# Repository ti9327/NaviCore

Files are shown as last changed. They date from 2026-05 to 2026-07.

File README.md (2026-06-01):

<div align="center">

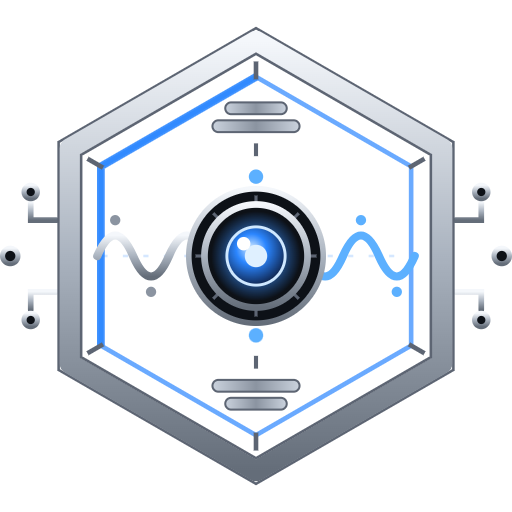
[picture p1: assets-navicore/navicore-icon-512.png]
NaviCore


# NaviCore

**Astromech Animation Controller**

[**🚀 Launch the config tool →**](https://greghulette.github.io/NaviCore/)

</div>

---

WCB-based RC controller firmware for ESP32-S3 (WCB HW 3.2). Reads SBUS from an
RC receiver, dispatches matrix buttons / switches / knobs to local and remote
Maestros and WCB boards over ESP-NOW, and ships with a browser-based config
tool that talks to the board over Web Serial.

## Features

- SBUS input (16 or 24 channel, auto-detected) on Serial1 (UART1)
- SBUS output passthrough on a dedicated hardware UART (UART0, GPIO9) — byte-tee
  of the RX stream, sub-millisecond latency (~1 byte-time)
- Local Pololu Maestro on Serial2 (UART2)
- Up to 8 remote Maestros via WCBStream broadcast over ESP-NOW
- WCB unicast and broadcast command dispatch
- Multi-mode (3-position switch) button / switch / knob mapping, NVS-backed
- Multi-tap detection (single / double / triple) with exclusive or cumulative
  dispatch
- USB Serial JSON protocol for config tool and CLI debugging

## Layout

```
NaviCore.ino         Main sketch
rc_config.h          Config struct, JSON serialisation, NVS persistence
wcb_config.h         WCB board ID / port definitions
sbus_reader.h        SBUS decoder + passthrough tee
config_tool/         Browser-based config GUI (Web Serial)
assets-navicore/     NaviCore brand assets (logo, favicon, app icons)
model/               FrSky X18 transmitter model file (download below)
```

## Required libraries

Install via the Arduino Library Manager:

- `ArduinoJson` (Benoit Blanchon) v6.x
- `Adafruit NeoPixel`

Local libraries (drop into your sketchbook `libraries/` folder):

- `WCBClient` + `WCBStream`
- `PololuMaestro`
- `hcr`

## Downloads

### FrSky X18 transmitter model

NaviCore assumes a specific channel map (SBUS channels 1–15 for
sticks/switches, CH7 for the button matrix, etc.). To save you setting all
that up by hand on your X18, the matching transmitter model file is bundled
in the [`model/`](model) folder.

- [**Download:** r2 web gui.bin](<model/r2 web gui.bin>) — ~2.4 KB

Copy it to the `MODELS/` folder on the X18's SD card, then load it from the
transmitter's model select screen.

## Configuration tool

Open [`config_tool/index.html`](config_tool/index.html) directly in a
Chromium-based browser (Chrome, Edge). Click **Connect**, pick the board's
serial port, and you get live PWM monitoring, button mapping, switch / knob
config, calibration, and CSV import/export.

The tool uses the [Web Serial API](https://developer.mozilla.org/en-US/docs/Web/API/Web_Serial_API)
— no install, no server, no Electron app.

## USB serial JSON protocol

Newline-delimited JSON on the USB Serial port:

| Command | Reply |
|---|---|
| `PING` | `{"type":"PONG"}` |
| `GET_CONFIG` | `{"type":"CONFIG","data":{...}}` |
| `{"type":"SET_CONFIG","data":{...}}` | `{"type":"ACK","ok":true}` |
| `{"type":"START_MONITOR"}` | streams `PWM_UPDATE` every 50 ms |
| `{"type":"STOP_MONITOR"}` | `{"type":"ACK","ok":true}` |
| `{"type":"RESET_DEFAULTS"}` | reloads factory defaults, replies ACK |
| `{"type":"TRIGGER","mode":1,"btn":3,"tap":1}` | fires virtual button press |
| `{"type":"WCB_SEND","target":2,"cmd":":PP100"}` | manually fires WCB command |

## Brand

NaviCore's mark is a machined hexagon housing a glowing photoreceptor, with the
RC signal arriving as a waveform (steel in, blue out). Logo, favicon, mono, and
app-icon assets live in [`assets-navicore/`](assets-navicore).

## License

MIT — see [LICENSE](LICENSE).

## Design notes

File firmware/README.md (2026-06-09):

# Firmware Binaries

This folder hosts the compiled NaviCore firmware for the **WCB v3.2**
hardware (ESP32-S3). The browser-based flasher in `config_tool/index.html`
(Config → Firmware tab) pulls the latest set from here on `main` via the
GitHub Contents API.

## Versioning

The firmware version is stored in `fw_version.h` at the repo root:

```c
#define FW_VERSION_BASE  "v0.2.0"         // bump by hand for releases
#define FW_VERSION_DTG   "211520QMAY26"   // auto-stamped by pre-commit hook
#define FW_VERSION       FW_VERSION_BASE "_" FW_VERSION_DTG
```

- **`FW_VERSION_BASE`** — semver version (MAJOR.MINOR.PATCH).  Edit by hand
  when cutting a new release: `v0.2.0` → `v0.2.1` → `v0.3.0` → `v1.0.0`.
  The build scripts treat the field as opaque — any quoted string works,
  so two-digit forms (`v0.1`) still parse if you need them.
- **`FW_VERSION_DTG`** — stamped automatically by `tools/git-hooks/pre-commit`
  on every commit, same DTG format as the UI footer in `config_tool/index.html`.
  Both files always reflect the same commit time.
- **`FW_VERSION`** — convenience macro the firmware uses to report itself
  in the `PONG` reply and at boot.

The build script reads both `#define`s and embeds them in the bin filename
(e.g. `NaviCore_v0.2.0_211520QMAY26_ESP32S3.bin`), so the file on disk,
the file's reported version at runtime, and the source header all match.

## File naming

Three files per release, all ending with these stable suffixes:

| File suffix | Flash address | What it is |
|---|---|---|
| `_ESP32S3.bin` | `0x10000` | Application image (`ota_0`)|
| `_ESP32S3_boot.bin` | `0x0` | Second-stage bootloader |
| `_ESP32S3_part.bin` | `0x8000` | Partition table |

The flasher matches by **suffix**, so the version prefix can change every
build without touching the page. Example set:

```
NaviCore_201500RMAY26_ESP32S3.bin
NaviCore_201500RMAY26_ESP32S3_boot.bin
NaviCore_201500RMAY26_ESP32S3_part.bin
```

The Config → Firmware tab offers two buttons:

- **⬆ Update Firmware** — routine update. NVS at `0x9000` is never touched,
  so the user's saved configuration survives.  The flasher auto-detects
  whether app-only is safe (matching partition table) or a full
  bootloader+partition+app write is needed (layout changed) — either way,
  NVS is preserved.
- **⚠ Full Wipe & Flash** — initial push / recovery.  Writes the full image
  AND erases NVS (`0x9000`, 20 KB) and OTA data (`0xE000`, 8 KB), returning
  the board to factory-fresh state.  Use this for first-time programming on
  a new board, or to recover from corrupted config / bad partition state.
  **Erases all saved settings.**

## How to update the binaries

**Default: GitHub Actions does it automatically.**  Every push to any
branch triggers `.github/workflows/build-firmware.yml`, which compiles
`NaviCore.ino` for ESP32-S3 with the `min_spiffs` partition scheme,
reads `FW_VERSION_BASE` + `FW_VERSION_DTG` out of `fw_version.h`, and
commits the three resulting bins back to `firmware/` (overwriting older
versioned files) under an auto-commit tagged `[skip ci]`.  Once that
commit lands on `main`, the Config → Firmware tab can flash any
connected board.

The two manual options below remain available for offline work or for
producing a one-off bin without going through CI.

### Option A — Arduino IDE (zero scripting)

1. Open `NaviCore.ino` in Arduino IDE.
2. Tools → Board → **ESP32S3 Dev Module** (or whatever you normally use for WCB v3.2).
3. Tools → Partition Scheme → **Minimal SPIFFS (1.9MB APP with OTA / 190KB SPIFFS)**.
4. Tools → PSRAM → **OPI PSRAM** — **required**; the firmware allocates its
   runtime config in external PSRAM and halts at boot (solid red status LED)
   without it.
5. Sketch → **Export Compiled Binary** (Ctrl/Cmd+Alt+S).
6. The IDE writes three files into `build/<fqbn>/`:
   - `NaviCore.ino.bin`
   - `NaviCore.ino.bootloader.bin`
   - `NaviCore.ino.partitions.bin`
7. Copy them into `firmware/`, renaming with a version prefix + the suffixes
   in the table above. Example:
   ```
   cp build/.../NaviCore.ino.bin             firmware/NaviCore_<DTG>_ESP32S3.bin
   cp build/.../NaviCore.ino.bootloader.bin  firmware/NaviCore_<DTG>_ESP32S3_boot.bin
   cp build/.../NaviCore.ino.partitions.bin  firmware/NaviCore_<DTG>_ESP32S3_part.bin
   ```
   (Old versioned files can be deleted or left as history — the flasher only
   looks at suffixes, so it always picks one of each.)
8. Commit to `main`. The Config → Firmware tab will pick them up automatically.

### Option B — `tools/build-firmware.ps1` (Windows) or `build-firmware.sh` (Linux/macOS/WSL)

Wraps `arduino-cli` so steps 2–6 above happen in one command.  Same
logic the CI workflow uses, just running locally.

```powershell
# Windows:
pwsh tools/build-firmware.ps1
```
```bash
# Linux / macOS / WSL:
tools/build-firmware.sh
```

Both read `FW_VERSION_BASE` + `FW_VERSION_DTG` from `fw_version.h`,
compile with the right FQBN + partition scheme, prune older bins, and
drop the new ones into `firmware/` with the matching version prefix.
You commit + push manually after a local build.

Prereqs: `arduino-cli` on `PATH`, the `esp32` core installed
(`arduino-cli core install esp32:esp32@3.3.4`), and the same library set
the CI workflow installs (see `.github/workflows/build-firmware.yml`).

## Notes

- Only **WCB v3.2** (ESP32-S3) is supported by the in-browser flasher right
  now. If support for older boards is added later, mirror the WCB Wizard's
  per-variant suffix scheme (`_ESP32.bin`, `_ESP32_boot.bin`, etc.) and add
  a board-variant dropdown to the Firmware tab.
- The flasher auto-detects whether the board is blank, has matching
  partitions, or needs a full flash. App-only is the default for any
  already-programmed board with a matching partition table.
- The page fetches from `main` by default. Developers can override the
  branch by setting `localStorage.rc_fw_branch = '<branch-name>'` in DevTools.

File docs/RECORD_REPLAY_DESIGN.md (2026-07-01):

# NaviCore Record / Replay — Design Spec (v2, validated)

Status: **DESIGN — validated against code, ready for phase-1 build.**
Last updated 2026-06-30. v2 folds in a 22-agent validation pass (see §12 changelog).

## Goal

Capture everything the droid *does* (Maestro moves, HCR, WCB commands, MP3, aux serial) over a
bounded window, save it as a named **clip**, replay it on demand, and build a renamable **library**
of clips. Phase 2 adds a **timeline editor** in the config tool. The phase-1 data model is designed
so phase 2 is purely additive.

## Decisions locked

1. **Servo anti-snap:** snapshot last-commanded positions at clip start (`servoHome`) → ease-in.
2. **Storage:** a **dedicated `clips` partition** carved from the 16 MB flash (OTA + config untouched).
3. **Motion smoothness:** prioritized — **dense keyframe capture (no thinning) + replay interpolation**.
4. **Trigger:** **button-first**. `toggle` is the universal button mode; `level`/`hold` need a switch.

---

## 1. Event model — a clip event is a timestamped `RcAction`

Every button/switch maps to an **`RcAction`** (`{type, target[6], cmd[96], fn, chan, track, note}`,
rc_config.h) that the config tool already renders (action picker) and serializes
(`actionToJson`/`actionFromJson`). So **clip event = `{ tMs, RcAction }`**, and the phase-2 editor is
that picker on a timeline.

### Capture taps (verified) — both route through ONE queue

| Tap | Captures | Core |
|---|---|---|
| `rcExecuteActionNow()` (NaviCore.ino:926) | Every discrete action (WCB uni/broadcast, Maestro, Serial, HCR, MP3) | **Core 1 AND Core 0** ⚠ |
| `processKnobs()` sinks — `maestroSetTarget` (:1196), `dispatchHcrVolume` (:1199) | Continuous gimbal/knob streams (synthesized as `setTarget`/`SetVolume` events) | Core 1 |

⚠ **`rcExecuteActionNow` runs on Core 0** for a remote ESP-NOW TRIGGER (`onWCBCommand` →
`rcTelemetry::handle` → `rcDispatch` → `rcExecuteActionNow`, rc_telemetry.h:863-871, no defer to
loop). It also runs on Core 1 (local press, `checkPendingActions`, Web-Serial TRIGGER). This dual-core
reachability **dictates the recorder's concurrency design** (§6) — it is the exact class of bug that
crashed the board during the OTA work.

---

## 2. Clip structure — baseline header + event list

The header snapshots the **global state** the events silently depend on.

| Header field | Why |
|---|---|
| `version, name[32], durationMs, createdDtg` | Metadata (tool stamps real date on save). |
| `mode` (1–3) | Context. |
| `boardType` + `auxBaud[3]` | A clip replayed on the *other* board profile (v2 PCB vs WCB 3.2) would mis-route / mis-speed local serial; record so the tool can warn on mismatch. |
| `hcrDest` {transport, target[6], wcbPort} | HCR actions carry only `fn/chan/track`; destination is **global**. |
| `mp3Dest` {transport, target[6]} | Same — MP3 destination is global. |
| `maestros[8]` {type, device} | Maestro actions carry a **logical slot id**; wiring + Pololu device # live here. |
| `hcrLocalVol[3]`, `mp3LocalVolume` | Volume **shadows** — restore before replay so relative *volume* ops replay deterministically. |
| `servoHome[]` {slot, ch, pos} | Last-commanded position per **slot+ch** (see §6) at clip start → ease-in. Excludes channels never driven or invalidated by `goHome` (sentinel `0xFFFF`). **Key strictly by slot id (1–8), never device#** — two slots may legally share a device# on different buses (NaviCore.ino:432-434), so a device#-keyed shadow would alias two servos. |

### Event records (tagged, timestamped)

| Tag | Record | ~size |
|---|---|---|
| `0x01` Action | `tMs, type, fn, chan, track, targetLen, cmdLen, target[], cmd[]` | 12–40 B |
| `0x02` Maestro keyframe | `tMs, slot, ch, pos(qus)` | ~8 B |
| `0x03` HCR-volume keyframe | `tMs, chan, vol` | ~7 B |

(`tMs` may be a `u16` delta on dense streams — encoding detail; clips ≤30 s.)

---

## 3. Continuous capture & smooth replay

- **Capture: dense, no thinning** — keep every change-gated keyframe (knob deadband 5 / volume 80 ms),
  so replay is at least as smooth as the live move.
- **Replay: interpolated** — the player holds each active `(slot,ch)` curve and emits the
  linearly-interpolated qus position **every loop tick**, decoupling smoothness from loop jitter.
- **Replay preconditions (mandatory) — reset device/cache state so interpolation is authoritative:**
  1. **Force Maestro `speed=0, accel=0`** (unlimited) on every `(slot,ch)` the clip drives before
     easing to the first `servoHome`. Latched Pololu speed/accel limits live *device-side* and would
     **double-smooth** the interpolated stream (distorted, non-deterministic). Read-back is impossible
     on the one-way bus, so we force-reset (don't snapshot). *(setSpeed/setAccel are excluded from
     capture — see §5.)*
  2. **Do NOT emit `0x03` HCR-volume keyframes through `dispatchHcrVolume()`** — its static
     `hcrVolCache` (NaviCore.ino:1128: value-dedupe + 80 ms/channel gate) is a live singleton that
     would drop the leading keyframe and decimate the stream. Emit them via a **raw** HCR path (build
     `RA_HCR fn=17` → `executeHcrAction()` directly), bypassing the cache. (`maestroSetTarget` needs no
     such treatment — it's a cacheless raw write.)
  3. **`goHome` is a curve discontinuity** (see §6) — on replaying a captured `goHome`, clear the
     affected slot's active interpolation curves so the next keyframe re-anchors from home.
- **Position is absolute qus**; the editor changes throw by scaling qus around a pivot.
- **Remote (broadcast) Maestro** smoothness is bounded by `WCBStream`'s 2 ms-gap flush — same as live.

---

## 4. Fidelity rules

- **Replay re-dispatches through the same path** (`rcExecuteActionNow` → `executeHcrAction`/…), so the
  emotion-`chan=4`→Overload rewrite, numeric-vs-readable-verb WCB encoding, and absolute-volume
  derivation re-apply for free. Store the raw `RcAction`; the dispatcher does the rest.
- **Relative *volume* ops are deterministic** (HCR VolumeUp/Down, MP3 Vol±) because the header restores
  the volume shadows.
- **MP3 `NEXT`/`PREV` are NOT deterministic on replay** — they advance the module relative to its live
  track pointer, which NaviCore doesn't shadow and the module won't read back. *Phase-1 policy:* mark
  them best-effort and recommend absolute `Play track` in recorded routines. *(Optional later: capture
  a `lastMp3Track` shadow and rewrite NEXT/PREV→absolute PLAY at capture — with residual drift if the
  module auto-advances on track end.)*
- **Timestamp encodes per-action delay** (we tap post-delay) → stored events use `delayMs=0`; replay
  schedules purely by `tMs`. **Order preserved** (cumulative tap tiers in true fire order).

## 5. Exclusions (never captured)

Telemetry (`rc_hb/rc_ch/rc_trig/rc_mode`), bridge housekeeping (`?WHOAMI`/PONG/STATUS), system
(reboot, config, calibration, debug flags, monitor toggles, OTA), the **Record/Play meta-functions**,
and **Maestro `setSpeed`/`setAccel`** (the player owns motion shaping via interpolation; re-dispatching
a latched limit would fight it). Recording auto-suppresses during calibration.

---

## 6. Recorder mechanics — concurrency is the critical part

**Single producer-safe queue, single PSRAM writer.** Because `rcExecuteActionNow` runs on both cores
(§1), the recorder MUST mirror the proven OTA / remote-CLI pattern:

- **Both taps enqueue** a fixed POD event (`{tMs, RcAction}`, ~144 B) into ONE FreeRTOS queue via a
  `static __attribute__((noinline))` helper doing only `xQueueSend(q, &ev, 0)` (non-blocking,
  drop-if-full). **No alloc, no flash, no mutex, no Serial, no large stack frame** in the tap — the tap
  sits 4 frames deep on the Core-0 ESP-NOW stack on top of the ArduinoJson parse; the `noinline` + small
  POD is exactly the `queueRemoteCli` fix that resolved the prior WiFi-task stack overflow
  (NaviCore.ino:1338-1347). Drop-if-full is acceptable (a dropped keyframe thins one frame).
- **`drainRecorder()` in `loop()` (Core 1)** — placed by `drainOtaPackets()`/`drainRemoteCli()`
  (NaviCore.ino:2246/2252) — is the **sole** writer/serializer of the PSRAM grow buffer (all
  realloc/append on Core 1 only; no mutex on the buffer needed).
- **Create the queue in `setup()` BEFORE `wcb->begin()`** (cf. `remoteCliQueue`) or the first remote
  TRIGGER hits a null queue.
- **Capture-enable flag is `volatile`/atomic** (read once at top of tap), gated off during replay so
  re-dispatched events aren't re-recorded.
- **Live buffer:** PSRAM grow buffer (8 MB — trivial), bounded to **30 s** + a hard byte cap. Flash
  touched only on save.

**`lastPos` shadow (for `servoHome`):** a `volatile uint16_t lastPos[8][32]`, init to `0xFFFF`
(never-commanded sentinel). `maestroSetTarget(slot,ch,pos)` writes `lastPos[slot-1][ch] = pos` — a
single naturally-aligned 16-bit store, **lock-free and torn-write-free on Xtensa** even across cores.
**Do NOT add any bitmap/counter/dirty-list RMW** in that tap (that would be the real race). At
clip-start the recorder snapshots `lastPos` on Core 1 (skipping `0xFFFF`).

**`goHome` invalidates the shadow + curve:** `goHome`/`stopScript`/`restartScript` bypass `setTarget`,
so hook `maestroGoHome(slot)` to set `lastPos[slot-1][*] = 0xFFFF` for all channels (home pose unknown
→ omit from `servoHome`); the player clears that slot's active curves when it re-emits `goHome`.

**Save / replay:** stop → serialize header+events to `clip<N>.ncr` in the clips FS. Replay → restore
shadows → reset speed/accel → ease to `servoHome` → schedule events by `tMs`, interpolating curves;
**suspend live dispatch** and gate capture off.

---

## 7. Trigger model — configurable, button-first

Two new mappable functions (`RA_RECORD` / `RA_PLAY`, excluded from capture), assignable via the
existing mapping UI. Their toggle/active-recording state is new module-level state on the Core-0/Core-1
boundary → keep it `volatile`/atomic.

- **Record**, param `mode`:
  - `toggle` *(default; the only matrix-button-safe mode)* — activate → start; again → stop+save.
  - `level` / `hold` — **require a switch** (or a momentary switch wired as a 2-position channel):
    `processSwitches` surfaces both edges as position changes (NaviCore.ino:1097); **matrix buttons
    deliver only a debounced tap-count, never a release/duration**, so `hold` is infeasible there.
  - param `slot`/`name` — where the capture saves.
- **Play**, params: `clip`, `loop`, `stopOthers` — fires on a button press or switch position.

Handheld (button-only) path: **Record(toggle) + Play(button)** — fully supported. *(A future handheld
on its own protocol could enable `hold` only if it reports button release; the SBUS matrix does not.)*

---

## 8. Storage — dedicated `clips` partition

The shipped table is **stock `min_spiffs`, topping out at 0x400000 (4 MB)** even though the module is
16 MB — leaving **12 MB free** above. Decoded current rows (keep byte-identical) + one appended `clips`
row:

```
# name,    type, subtype,  offset,    size
nvs,       data, nvs,      0x9000,    0x5000
otadata,   data, ota,      0xE000,    0x2000
app0,      app,  ota_0,    0x10000,   0x1E0000
app1,      app,  ota_1,    0x1F0000,  0x1E0000
spiffs,    data, spiffs,   0x3D0000,  0x20000     # config.json — MUST stay byte-identical
coredump,  data, coredump, 0x3F0000,  0x10000
clips,     data, spiffs,   0x400000,  0xC00000    # NEW — 12 MB, fills the 16 MB flash
```

- **Config FS survives only if the `spiffs` row is unmoved.** `rc_config.h` mounts
  `LittleFS.begin(true)` (format-on-fail) bound to the default `spiffs` label — shift/resize that row
  and `config.json` is **silently reformatted**.
- **Mount `clips` as a SECOND LittleFS by label + distinct base path:**
  `LittleFS.begin(true, "/clips", 10, "clips");`. Format is scoped to the `clips` label, so first-boot
  format can never touch config.
- **Build wiring (these files change together — `.github/workflows` is NOT touched, only `tools/`):**
  - Add `NaviCore/partitions.csv` (the 7 rows above).
  - `tools/build-firmware.ps1` **and** `tools/build-firmware.sh`: FQBN `PartitionScheme=custom` +
    `FlashSize=16M`. **`build-firmware.sh` must also copy the custom 16 MB
    `WCB_S3_custom_bootloader_16MB_wdt3s.bin`** (it currently copies arduino-cli's 4 MB stock — the
    `.ps1` already copies the custom one). Otherwise CI republishes a stock table+bootloader and
    **reverts** the change (the workflow auto-commits `firmware/*.bin`).
  - Update doc/comment mentions of `min_spiffs` in `firmware/README.md`, `build-firmware.ps1`, and the
    `flasher.js` layout comments (lines ~91-95 / ~279-284). `flasher.js` *logic* needs no change — it
    writes `part.bin@0x8000` unconditionally and never keys off the config/clips offsets; the otadata
    (0xE000) / NVS (0x9000) erase set is fixed and must **never** be broadened to a full-chip erase.
- **Go/no-go gate:** after building, decode the emitted `_part.bin` and assert rows 0–5 are byte-identical
  to the current shipped `_part.bin` and row 6 is `clips@0x400000`. The 16 MB bootloader is already
  confirmed (`byte[3]=0x4f`; flasher uses `flashSize:'keep'`).
- **Migration:** the `clips` partition arrives via a **full flash** of the locally-built bins (the
  in-browser flasher writes boot+part+app). App-only **OTA** doesn't touch the table, so OTA keeps
  working after migration.

---

## 9. Config-tool integration

A **Clips** panel: list / rename / delete / play, transferred via a small **clip↔JSON bridge** (reuse
`actionToJson` per event) over the existing WCB-bridge/USB JSON transport. Phase 2 (**built**, see §13):
a 📈 button on each clip row opens a **timeline editor** — servo/HCR-volume curves as draggable keyframes,
an easing tool, and an Actions row for adding/editing/deleting discrete commands (WCB/HCR/MP3/serial/
Maestro/record/play/stop) — writing the clip back via a new `EDITBEGIN/EDITEV/EDITEND` upload transport.

## 10. Phase plan

- **Phase 1 (built):** `partitions.csv` + build wiring + clips FS mount; recorder (queue tap → Core-1 drain →
  PSRAM buffer, `lastPos` shadow, `goHome` invalidation, save); player (restore shadows + reset
  speed/accel + ease-in + interpolated replay, HCR-volume cache bypass); `RA_RECORD`/`RA_PLAY`
  functions; config-tool Clips panel.
- **Phase 2 (built, see §13):** timeline editor — download/edit/upload transport + SVG editor UI.

## 11. Resolved risks (from validation) + residual

- ✅ Core-0 capture safety → single non-blocking queue, `noinline` small-POD tap, Core-1 sole writer.
- ✅ Partition brick/wipe → keep `spiffs` byte-identical, 2nd labeled mount, CI scripts emit custom table.
- ✅ Maestro speed/accel double-smoothing → reset on replay + exclude from capture.
- ✅ HCR-volume cache decimation → bypass `dispatchHcrVolume` on replay.
- ✅ `goHome` shadow/curve desync → invalidate shadow + clear curve.
- ✅ `hold` infeasible on matrix buttons → `toggle` for buttons, `hold`/`level` for switches.
- ⚠ Residual (documented, low-impact): MP3 NEXT/PREV non-deterministic; slot/device aliasing affects
  only ease-in pre-roll (config already illegal); cross-board replay mismatch (header warns).

## 13. Phase 2 — timeline editor (built 2026-07-01, config-tool-verified; NOT hardware-tested)

Opened via a new **📈** button on each Clips-panel row (`openTimelineEditor(name)`). Ground truth stays the
on-device `.ncr` file — the editor downloads a clip, edits it client-side, and uploads the result back;
`navicore_record.h` gained no new persistence format, it reuses `_buf`/`_count`/`saveClip()` exactly like
LOAD/SAVE already do.

**Wire protocol — two directions, two different integrity strategies (both `?REC,*` CLI sub-verbs):**

- **Download** (`EDITLOAD,<name>`, read-only against `_buf`): `loadClip()`s, then streams every event as one
  small JSON line — `[CLIPDL:BEGIN]{count,durationMs,mode}` → `[CLIPDL:EV]{t,k,...}` × N → `[CLIPDL:END]`.
  Same "small self-contained line" shape as the [CLIPLIST]/[CLIPITEM] fix (§ earlier bugfix) so a line can't
  be hard-wrapped mid-JSON by the WCB RTERM sink's 160-byte packet limit (a maximal action event — a 95-char
  WCB `cmd` — CAN exceed 160 B, so the config tool applies the SAME per-source fragment-reassembly it already
  uses for the old single [CLIPLIST] marker). No per-line ACK: a lost/incomplete download is read-only (no
  device state mutated) and trivially retried, so the config tool just checks the BEGIN-declared `count`
  against events actually received and shows a clear error + retry prompt on mismatch — full OTA-grade
  ACKing would be overkill for something this cheap to just redo.
- **Upload** (`EDITBEGIN` → `EDITEV,<json>` ×N → `EDITEND,<name>`): this WRITES, so a lost event would
  silently corrupt the saved clip — needs real integrity. Per-event ACK/NAK with retry, mirroring naviota's
  OTA DATA/ACK contract: `[CLIPUL:BEGIN,OK|ERR]`, `[CLIPUL:ACK,<count>]`/`[CLIPUL:NAK,<reason>]` per event
  (3 attempts, then abort), `[CLIPUL:END,OK|ERR,<reason>]`. A NEW firmware state, `ST_EDITING`, brackets the
  whole upload — every existing entry point (`startRecord`/`startReplay`/etc.) already gates on
  `_state==ST_IDLE`, so adding one more state value automatically fences a concurrent live Record/Play
  trigger out of stomping `_buf`/`_count` mid-upload, with zero other call sites needing to change. On
  finalize, `editEnd()` `qsort()`s `_buf` by `tMs` before saving — drag/insert/delete edits can leave events
  out of chronological order, which `clipDurationMs()`, the discrete-event replay cursor, AND the phase-1b
  curve-chain builder all assume is monotonic.

**Editor data model (client-side, `_tlClip`, config_tool/index.html):** flat downloaded events reshape into
`maestro["<slot>-<ch>"] = [{t,pos}]` / `hcr["<chan>"] = [{t,vol}]` (both sorted, keyframe arrays) + a flat
`actions[]` list. `action` objects are the EXACT SAME shape `actionToJson`/`actionFromJson` (firmware) and
`appendActionFields`/`readActionFromFid` (config tool) already use everywhere else — the whole point (per
§1's original "no-throwaway" principle) is that a timeline action is edited by the SAME code as a button
action, just at an arbitrary timestamp instead of a tap tier. `readActionFromUI(tier,ai)` was refactored
into a thin wrapper over a new `readActionFromFid(fid,type,extras)` so the button/switch/knob editors and
the timeline's action popover share one field-reading implementation instead of drifting apart.

**SVG timeline UI:** one row per Maestro `(slot,ch)` / HCR channel actually present in the clip (+ "add
track" buttons for a channel the clip doesn't touch yet), each a draggable-keyframe polyline; a shared
"Actions" row of diamond markers. Maestro positions are STORED in ¼µs (matches the wire `pos` field and the
firmware directly — zero conversion on save) but DISPLAYED/EDITED in µs, same UI convention as the
knob-passthrough Pos min/max fields added earlier this session, converted only at the render/drag boundary.
Click empty track space → add a keyframe/action at that time+value; click a point → select (Delete key
removes it); drag → move it (re-sorted on release); Shift-click a second ADJACENT keyframe on the same
track → arms an **easing** toolbar (linear/easeIn/easeOut/easeInOut + step count) that INSERTS synthesized
intermediate keyframes between the pair — the firmware only ever interpolates LINEARLY between whatever
keyframes exist (phase 1b), so this is the entire mechanism behind "easing": denser keyframes approximating
a curve, not a new firmware curve type. Re-applying easing to the same pair REPLACES the previously
synthesized points (filters anything strictly between the two anchors) rather than stacking more on top. A
draggable scrub cursor shows a live readout that mirrors the firmware's inter-keyframe linear interpolation
(`_tlInterpolateAt`, deliberately parallel to `navicore_record.h`'s `_updateCurves`) plus any actions within
±50 ms, so the user can preview values without hardware attached.

**Verified (browser, no hardware):** full download→model→render pipeline (maestro + HCR + action events);
fragment reassembly for a 191-byte action event split at the exact 160-byte RTERM boundary (reassembles to
the original, unfragmented over Direct USB); add/select/delete keyframes and tracks; easing insert AND
replace-not-stack re-apply; the action-editor popover (open/type-switch/apply/delete) round-tripping through
`readActionFromFid`; the FULL upload sequence (BEGIN→8×EV→END) with simulated ACKs; NAK-then-retry recovery;
a rejected EDITBEGIN failing cleanly with edits preserved (`dirty` stays true, nothing lost); an incomplete
download (declared count vs. received count mismatch) showing a clear error without building a bogus partial
model. Also regression-checked the existing button/switch/knob action editor through the refactored
`readActionFromUI`→`readActionFromFid` path — unaffected. Firmware (`navicore_record.h` + the `?REC,EDIT*`
CLI in `NaviCore.ino`) compiles clean. **NEXT: bench test** — a real clip loaded, edited (drag a servo curve,
add an HCR command, apply easing), saved, and replayed to confirm the round-trip actually drives the Maestro
as edited.

## 12. Changelog

- **v3.7 (2026-07-01):** **Record trigger always saves on stop** (firmware, needs reflash). `pollControl()`
  CTL_REC_TOGGLE stop branch now ALWAYS `saveClip()`s: to the action's configured name (overwrites that slot) or,
  when blank, an auto-generated `rec_N` (`_autoClipName` = lowest unused) — previously a blank name stopped WITHOUT
  saving (RAM-only, silently lost). Prints `[REC] saved clip '<name>'` on success (saveClip prints the reason on
  failure). So: named Record button = re-record-in-place (pairs with Play-by-name); blank = keep-every-take. Config
  tool Record-action hint updated to explain it. (`case CTL_REC_TOGGLE` wrapped in a block — it now declares locals.)
- **v3.6 (2026-07-01):** Clip-library ↔ trigger-action linkage (config-tool only). A Play/Record action references
  a clip by name (`cmd`), so: (a) **renaming a clip** re-points every matching action (`_renameClipRefs` over
  mappings `t1/t2/t3` + switch `p0/p1/p2`) so buttons keep working — with a client-side collide-guard mirroring the
  device's, and an offline guard; (b) **deleting a clip** offers (2nd confirm) to remove the now-dead trigger
  actions (`_removeClipRefs`); both prompt the user to Save (config changes are local until SET_CONFIG). (c) The
  **Play/Record action fields are now a combo** — an `<input list="clip-name-options">` backed by a shared
  `<datalist>` repopulated from every `?REC,LS` (`_updateClipNameOptions` in renderClips), refreshed (throttled,
  silent) when a play/record field renders — so you pick a real clip name from a dropdown but can still type one.
  Scan helpers guard bare mappings / 2-pos switches / null entries / missing config; knobs (no play/record) ignored.
- **v3.5 (2026-07-01):** Timeline **delete-whole-track** (red ✕ per track in the label gutter → `_tlDeleteTrack`,
  confirmed; config-tool only) + **save-failure diagnostics** (firmware, needs reflash). `saveClip()` now prints a
  SPECIFIC reason to the terminal per failure path (no clips FS / busy / empty / bad name / open failed / write
  failed); `editEnd()` returns a reason string forwarded as `[CLIPUL:END,ERR,<reason>]`, which the config tool
  surfaces in the Save-failed status. NOTE the original editEnd→saveClip ST_EDITING fix (v3 era) is a FIRMWARE
  change — a save still failing means the board is running pre-fix firmware; **reflash required.**
- **v3.4 (2026-07-01):** Timeline **double-click-drag = SOLO (single-point) keyframe drag** (config-tool only) —
  Greg wanted a way to nudge one dot without the smooth-drag pulling its neighbours. A second pointerdown on the
  SAME keyframe id within 350ms (`_tlKfDownStamp`) makes that gesture ignore the falloff (weight 1 for the grabbed
  dot, 0 for all others) regardless of the "Smooth drag" radius. Guards verified: a press on a different dot, or
  past the 350ms window, both stay smooth.
- **v3.3 (2026-07-01):** Timeline-editor delete + smooth-add (config-tool only), from Greg's feedback ("how do I
  delete dots? clicking anywhere makes a new one" + "clicking off the line makes a sharp angle"). Each keyframe
  now renders a display-only visible dot (`pointer-events:none`) under a larger **transparent r=11 hit circle**
  that carries the drag/select events — small dots were easy to miss, so mis-aimed clicks kept ADDING points.
  **Right-click a dot or an action diamond deletes it** (`contextmenu` → `_tlDeleteKeyframe`/`_tlDeleteAction`,
  preventDefault kills the browser menu); select+Delete/🗑 still work. **Snap-to-line on add:** clicking empty
  space to insert a keyframe BETWEEN two existing ones snaps its value onto the interpolated line when the click
  is within 8px of it (so a near-miss doesn't kink the curve — you add a control point then drag to shape);
  a deliberate off-line click still places a peak, and extending past the ends always uses the click value.
- **v3.2 (2026-07-01):** Timeline-editor zoom + trim (config-tool only). **Zoom** now preserves a focal point
  — `_tlZoomAt(factor, clientX)` converts the focal client-x to a clip time, rescales `pxPerMs`, then restores
  that time to the same viewport offset via `scrollLeft` (previously every zoom jumped back to t=0). Wired to
  the +/− buttons (view-centre focal), **Ctrl+scroll** over the timeline (focal = pointer, finer step,
  `preventDefault` suppresses browser page-zoom), and a new **⤢ Fit** button (`_tlFit`, sizes `pxPerMs` to the
  viewport width; guards `usable<=0` so an unlaid-out container can't apply a degenerate zoom). Max zoom raised
  2→4×. **✂ Trim start** (`_tlTrimStart`): shifts every event left by the earliest `t` so the clip starts at 0,
  removing leading empty space — non-destructive (no events deleted, just re-timed; undone by closing without
  saving), reduces `durationMs`/`cursorMs` accordingly, no-op with a status note when there's no leading gap.
- **v3.1 (2026-07-01):** Timeline-editor UX pass (config-tool only) + a review-driven bug sweep.
  - **Proportional ("soft") keyframe drag:** dragging a servo/HCR dot pulls its same-track neighbours by a
    cosine falloff over an adjustable radius (`_tlSoftRadius`, "Smooth drag ___ ms" toolbar field; 0 = classic
    single-point), so you get a smooth hump/warp instead of a spike. Purely editor-side — it just moves more
    keyframes; the firmware still only linear-interpolates. Also FROZE the dragged track's value range for the
    gesture (`_tlFrozenRange`) — fixes a latent jitter where the y-axis rescaled mid-drag so the dot drifted
    off the cursor.
  - **Draggable action markers:** the Actions-row diamonds now drag horizontally to reposition in time (>3px =
    drag, else click-to-edit) — previously click-only.
  - **Review sweep (4-lens adversarial review + verify workflow, 5 confirmed):** exception-safe + idempotent
    drag teardown (`finish()` guard) so window pointer listeners can't leak and a mid-drag editor-close can't
    crash on a null `_tlClip`; shift-select reads the shift state from the pointer**up** (not the stale
    pointerdown); `_tlToggleShiftSelect` recomputes both indices fresh (a re-sort can't stale the adjacency
    test into deleting keyframes between non-adjacent picks); `_tlFlattenEvents` dedupes same-`t` keyframes
    per track (keep-last) so a drag rounding two neighbours onto one ms can't emit a nondeterministic
    duplicate-`t` to firmware. **Plus a bug the review flushed out:** the easing PAIR selection was fully
    broken — `_tlStartDragKeyframe` cleared `selectedPair` up-front, so the 2nd shift-click always wiped the
    1st (easing math worked, but you could never select the pair through the UI). Now the pair clears only on
    a real drag or a plain click. All re-verified in-browser via simulated pointer gestures.
- **v3 (2026-07-01):** Phase 2 timeline editor built — see §13 for the full writeup. New firmware: `ST_EDITING`
  state + `editBegin/editAddEvent/editEnd/editCancel/editStream` in `navicore_record.h`; `?REC,EDITLOAD/
  EDITBEGIN/EDITEV/EDITEND/EDITCANCEL` CLI. New config tool: 📈 Clips-panel button, `tl-modal`/`tl-action-modal`,
  the whole `_tl*` editor module, `_clipDlFeed` (download reassembly), `_tlWaitForMarker`/`_tlFeedMarker`
  (upload ACK waiter), `readActionFromFid` (extracted from `readActionFromUI` for reuse).
- **v2.1 (2026-07-01):** Phase 1b (interpolated replay) implemented in `navicore_record.h`. Per-channel
  `MaestroCurve` + a `_curveNext[]` chain (parallel array, one forward O(n) pass per `startReplay()`) give
  `_updateCurves()` **look-ahead**: it eases from the last *finalized* keyframe (`pPrev`@`tPrev`) toward the
  next *not-yet-finalized* one (read live via `_buf[nextIdx]`), re-anchoring once elapsed reaches that
  keyframe's time — the anchor is always in the past and the target always in the future, which the naive
  "fire event, then look at what already happened" cursor loop can't give you (a keyframe is only knowable
  once its own timestamp arrives). `reanchor` implements the `goHome` discontinuity from §3.3: mid-replay it
  suppresses emission (servo pose is unknown — snapped to a Maestro-side home we can't read back) until the
  next keyframe for that channel lands, which then **snaps** rather than easing from a stale position. Loop
  mode (`_loop`) rewinds via `_rewindCurves()` (cheap — reuses each channel's precomputed `firstIdx`, no
  buffer rescan) rather than a full rebuild, keeping `pPrev` at wherever the previous lap actually left the
  servo so the loop seam eases instead of snapping. Emission is de-duped per channel (`lastEmitted`) so a
  flat curve doesn't spam Maestro serial writes every tick.
- **v2 (2026-06-30):** validated against code by a 22-agent pass. Added: dual-core capture truth +
  single-queue concurrency design; concrete partition CSV + config-FS-wipe guard + CI-revert fix
  (tools-only); replay speed/accel reset; HCR-volume cache bypass; `goHome` shadow/curve invalidation;
  `servoHome` slot-keying rule + `0xFFFF` sentinel; MP3 NEXT/PREV determinism correction; `hold`→switch
  scoping; header `boardType`/`auxBaud`.
- **v1:** initial design.

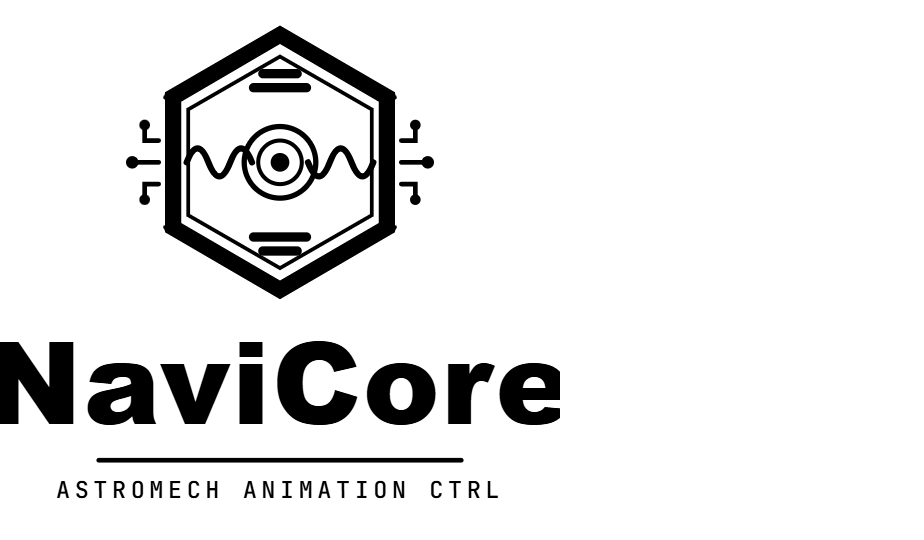
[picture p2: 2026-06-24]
PCB/NaviCore_V1/assets/navicore-pcb-black-on-white.png

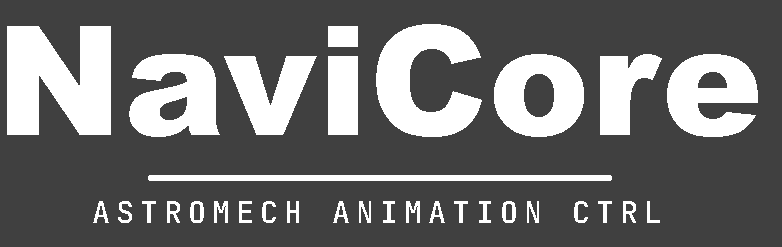
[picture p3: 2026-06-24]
PCB/NaviCore_V1/assets/Rc controller/assets-navicore/navicore-pcb-wordmark-white-on-transparent.png

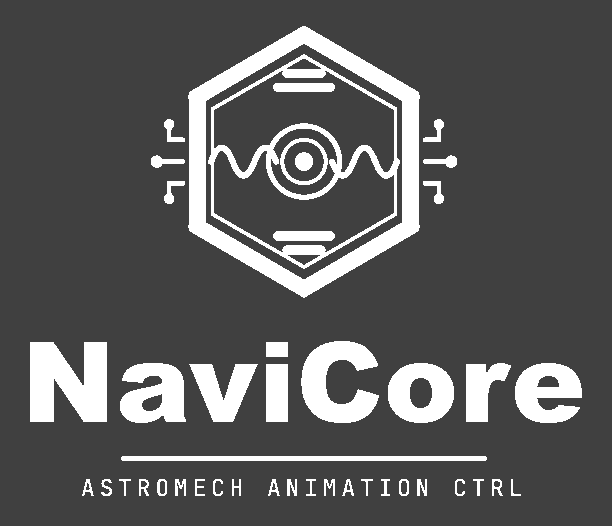
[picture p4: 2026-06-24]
PCB/NaviCore_V1/assets/Rc controller/assets-navicore/navicore-pcb-white-on-transparent.png

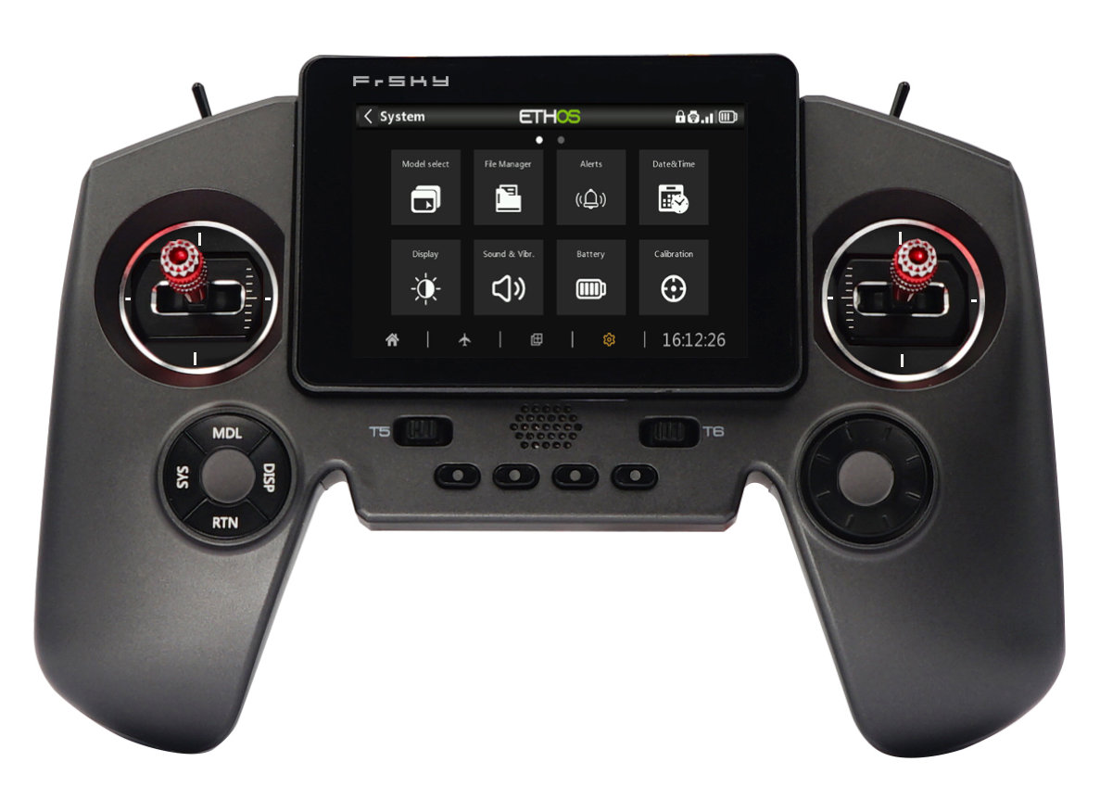
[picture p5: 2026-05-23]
Images/x-lite twin.jpg

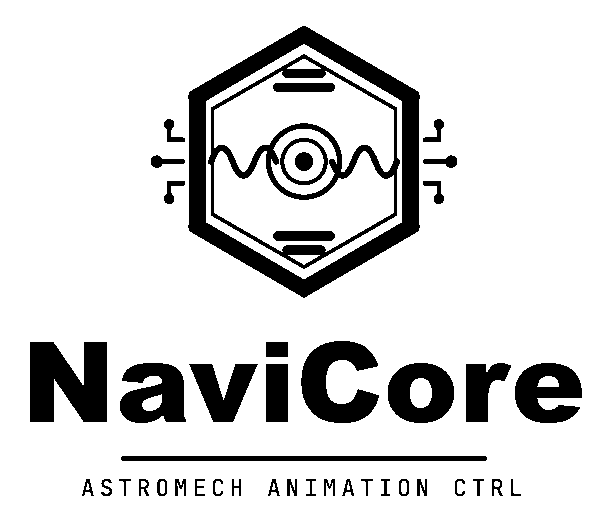
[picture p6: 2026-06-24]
PCB/NaviCore_V1/assets/Rc controller/assets-navicore/navicore-pcb-positive.png

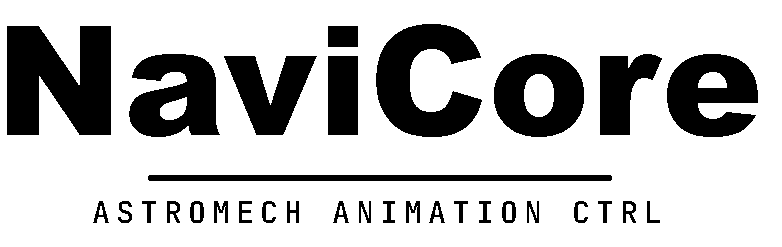
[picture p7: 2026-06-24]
PCB/NaviCore_V1/assets/Rc controller/assets-navicore/navicore-pcb-wordmark-positive.png

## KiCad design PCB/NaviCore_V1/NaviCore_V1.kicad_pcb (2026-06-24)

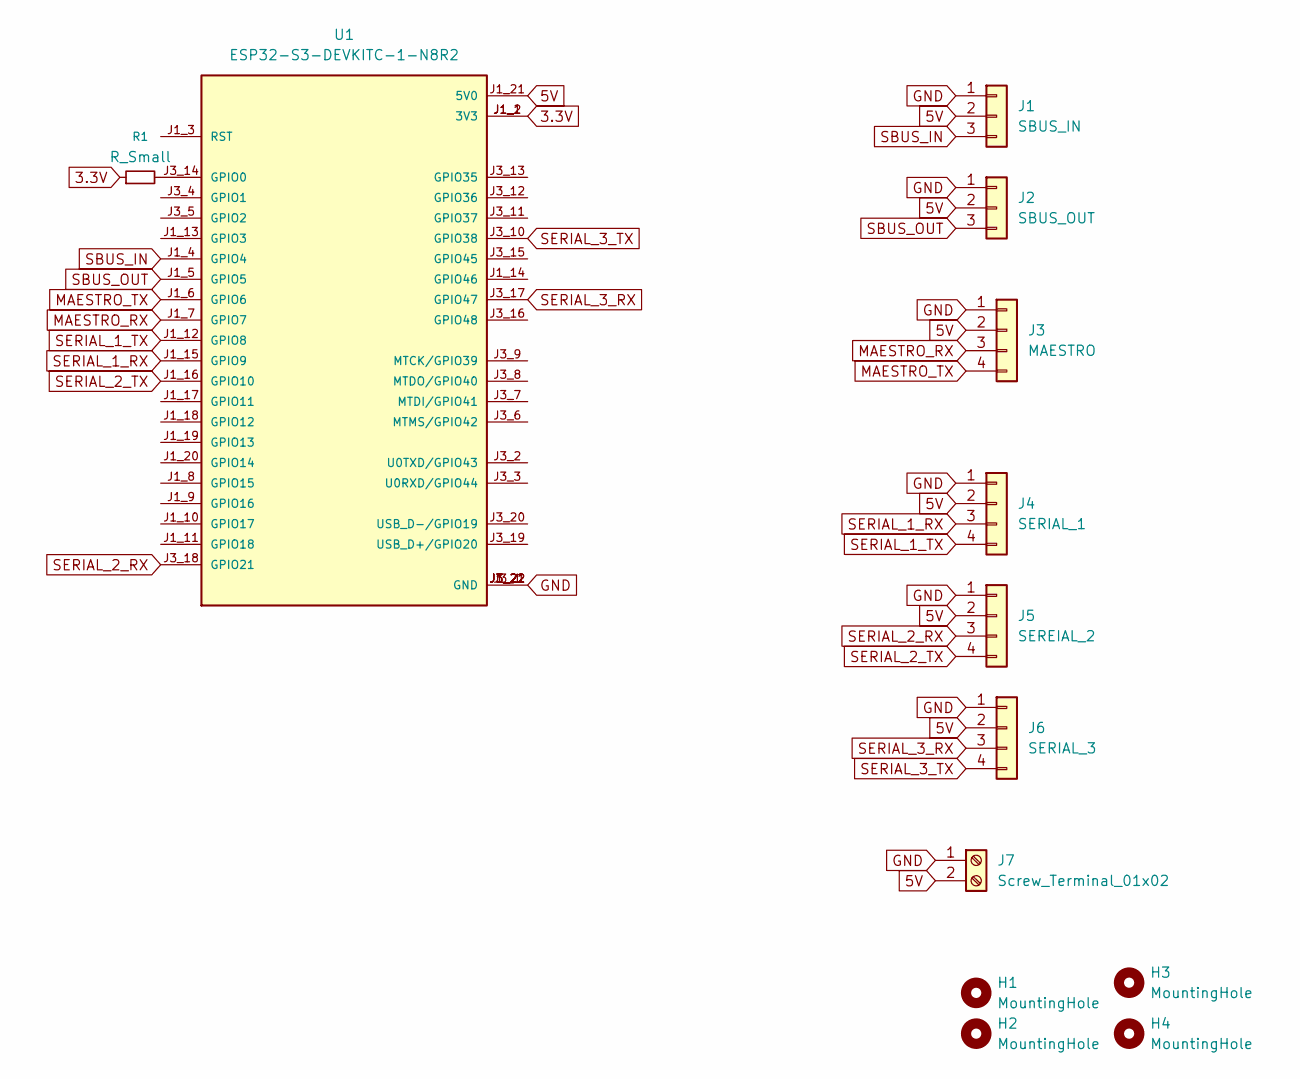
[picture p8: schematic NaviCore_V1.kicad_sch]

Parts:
H1, H2, H3, H4: MountingHole; MountingHole_3.2mm_M3
J1: SBUS_IN; PinHeader_1x03_P2.54mm_Vertical
J2: SBUS_OUT; PinHeader_1x03_P2.54mm_Vertical
J3: MAESTRO; PinHeader_1x04_P2.54mm_Vertical
J4: SERIAL_1; PinHeader_1x04_P2.54mm_Vertical
J5: SEREIAL_2; PinHeader_1x04_P2.54mm_Vertical
J6: SERIAL_3; PinHeader_1x04_P2.54mm_Vertical
J7: Screw_Terminal_01x02; TerminalBlock_Phoenix_MKDS-1,5-2-5.08_1x02_P5.08mm_Horizont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
R1: R_Small; R_Axial_DIN0309_L9.0mm_D3.2mm_P12.70mm_Horizontal
U1: ESP32-S3-DEVKITC-1-N8R2; XCVR_ESP32-S3-DEVKITC-1-N8R2; PARTREV V1

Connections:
3.3V: R1.1, U1.J1_1 (3V3), U1.J1_2 (3V3)
5V: J1.2, J2.2, J3.2, J4.2, J5.2, J6.2, J7.2, U1.J1_21 (5V0)
GND: J1.1, J2.1, J3.1, J4.1, J5.1, J6.1, J7.1, U1.J1_22 (GND), U1.J3_1 (GND), U1.J3_21 (GND), U1.J3_22 (GND)
MAESTRO_RX: J3.3, U1.J1_7 (GPIO7)
MAESTRO_TX: J3.4, U1.J1_6 (GPIO6)
unnamed: R1.2, U1.J3_14 (GPIO0)
SBUS_IN: J1.3, U1.J1_4 (GPIO4)
SBUS_OUT: J2.3, U1.J1_5 (GPIO5)
SERIAL_1_RX: J4.3, U1.J1_15 (GPIO9)
SERIAL_1_TX: J4.4, U1.J1_12 (GPIO8)
SERIAL_2_RX: J5.3, U1.J3_18 (GPIO21)
SERIAL_2_TX: J5.4, U1.J1_16 (GPIO10)
SERIAL_3_RX: J6.3, U1.J3_17 (GPIO47)
SERIAL_3_TX: J6.4, U1.J3_10 (GPIO38)

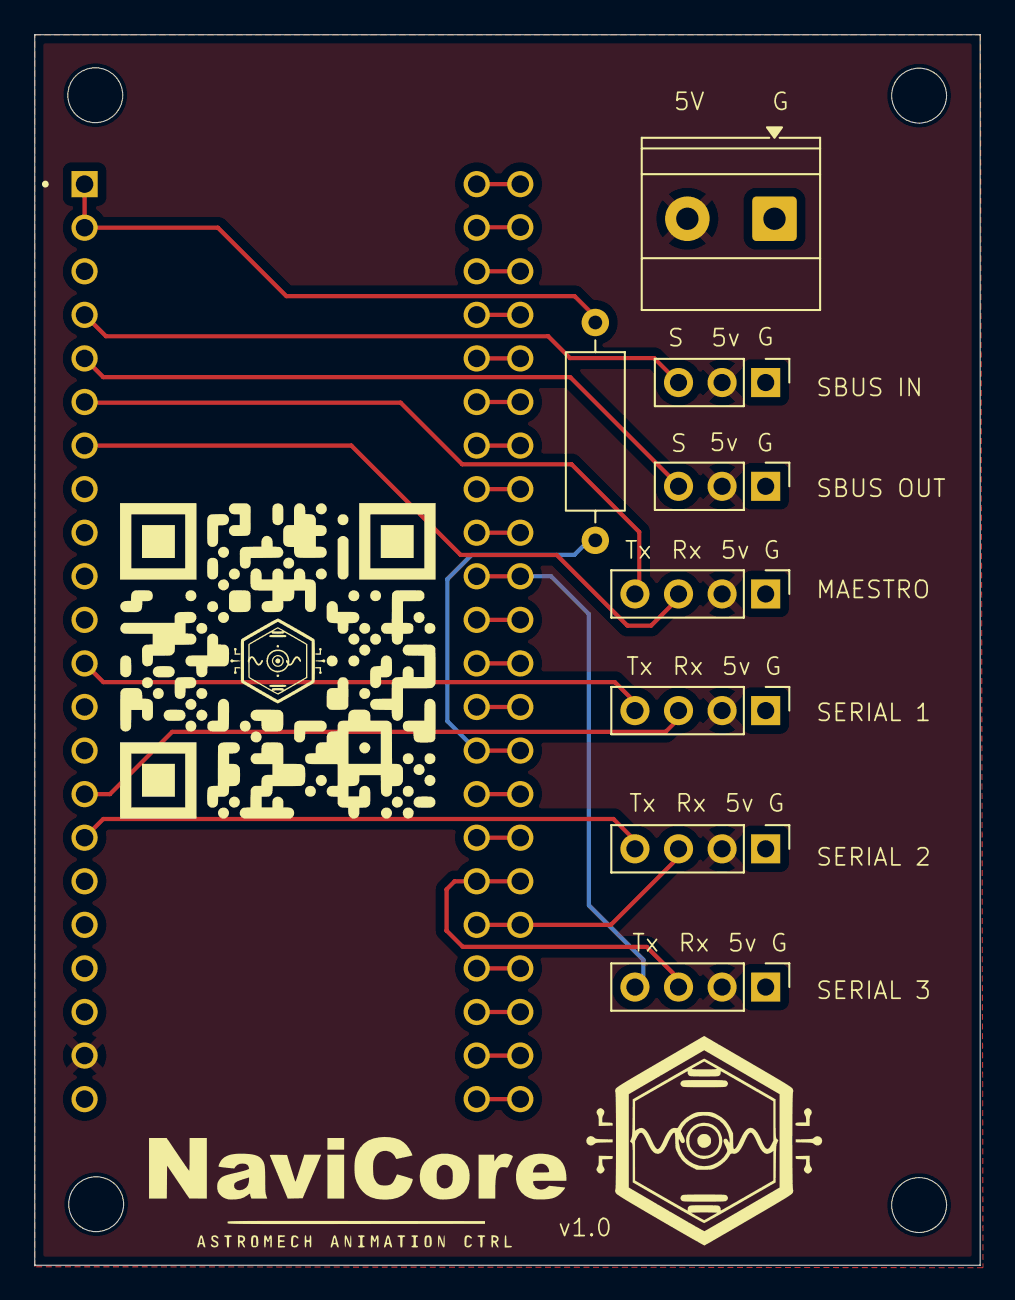
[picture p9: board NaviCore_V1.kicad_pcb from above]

Board: 2 copper layers, 55.1 x 71.7 mm, 13 parts (0 on the bottom side), 14 nets.

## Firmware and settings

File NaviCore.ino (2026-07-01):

// =============================================================================
//  NaviCore.ino — WCB-based RC Controller (formerly RC-Controller / HyperCore)
//  Target hardware: NaviCore v2 PCB (default) or WCB HW 3.2 — ESP32-S3,
//  selected at runtime by rcConfig.boardType (see applyBoardProfile()).
//
//  Features:
//    • SBUS input (16 or 24 channel, auto-detected) on shared UART1 RX
//    • SBUS output passthrough on the SAME shared UART1 TX (per board profile:
//      v2 GPIO5 / WCB 3.2 GPIO4) — byte-streamed re-emit of the RX frame so a
//      downstream device sees the same channel data
//    • Local Pololu Maestro on Serial2 @ 115200 baud (GPIO6 TX)
//    • Up to 8 remote Maestros via WCBStream broadcast over ESP-NOW
//    • WCB unicast and broadcast command dispatch
//    • Three aux serial ports S3/S4/S5 (S3 = hardware UART0; S4/S5 SoftwareSerial)
//    • Multi-mode RC button/switch/knob mapping (NVS-backed, GUI-configurable)
//    • USB Serial JSON protocol for config tool and CLI debugging
//      (open config_tool/index.html on your PC, connect via Web Serial API)
//
//  USB Serial JSON Protocol (newline-delimited):
//    PING                        → {"type":"PONG"}
//    GET_CONFIG                  → {"type":"CONFIG","data":{...full config JSON...}}
//    {"type":"SET_CONFIG","data":{...}} → {"type":"ACK","ok":true}
//    {"type":"START_MONITOR"}    → streams PWM_UPDATE every 50 ms until STOP_MONITOR
//    {"type":"STOP_MONITOR"}     → {"type":"ACK","ok":true}
//    {"type":"RESET_DEFAULTS"}   → reloads factory defaults, replies ACK
//    {"type":"REBOOT"}           → ACKs then restarts the board after 250 ms
//    {"type":"TRIGGER","mode":1,"btn":3,"tap":1} → fires virtual button press
//    {"type":"WCB_SEND","target":2,"cmd":":PP100"} → manually fires WCB command
//
//  Required libraries (Library Manager):
//    • ArduinoJson        (Benoit Blanchon) v6.x
//    • Adafruit NeoPixel
//
//  Local libraries (in libraries/ folder):
//    • WCB_Client + WCBStream  (from the greghulette/WCBClient repo)
//    • PololuMaestro
// =============================================================================

#include <Arduino.h>
#include <WiFi.h>
#include <ArduinoJson.h>
#include <Preferences.h>
#include <LittleFS.h>     // config persists as /config.json (replaces the NVS 4000-byte/value limit)
#include <SoftwareSerial.h>
#include <Adafruit_NeoPixel.h>
#include "esp_timer.h"          // one-shot boot-guard timer (cold-boot auto-recovery)
#include "esp_ota_ops.h"        // esp_ota_get_bootloader_description (boot banner)
#include "rom/rtc.h"            // rtc_get_reset_reason (low-level boot telemetry)
#include <WCB_Client.h>   // header in greghulette/WCBClient is WCB_Client.h
#include <WCBStream.h>
// HCR (Human Cyborg Relations Vocalizer): no library dependency — we format
// the same byte string the upstream HCRVocalizer would have written and push
// it directly to the bound aux-serial port.  See hcrFormatCommand() below.
#include "sbus_reader.h"
#include "rc_serial.h"     // USB-CDC tee — MUST precede project headers that print (remote-terminal capture)
#include "rc_config.h"
#include "wcb_config.h"
#include "fw_version.h"     // FW_VERSION_BASE / FW_VERSION_DTG / FW_VERSION
#include "rc_telemetry.h"   // WCB-network remote-management bridge (Phase 1 — see file header)
#include "navicore_ota.h"   // firmware OTA — ?OTALOCAL (direct USB) + ?OTA (ESP-NOW relay)
#include "navicore_rterm.h" // remote terminal — mirror CLI output back over the WCB bridge (RTERM)
#include "navicore_record.h" // record/replay — capture dispatched droid actions to a clip + replay

// USB-CDC tee instance backing the `#define Serial rcSerial` in rc_serial.h.
// Defined once here; setup()'s Serial.begin()/setRxBufferSize() drive it.
RcSerial rcSerial;

// Record/replay clip library filesystem — a SECOND LittleFS mounted on the
// dedicated 12 MB `clips` partition (partitions.csv), separate from the config
// LittleFS (`spiffs` label). Its own instance + label so a first-boot format is
// scoped to clips and can never touch /config.json.
fs::LittleFSFS clipsFS;
bool           g_clipsReady = false;

// Remote-terminal state.  A raw ?.../#... CLI line arriving over the WCB mesh
// (onWCBCommand, Core 0) is stashed here and run in loop() with its Serial
// output tee'd to rtermSink, which ships each line back to the relay (bridge)
// as an RTERM packet that surfaces on the config-tool terminal.
navirterm::CaptureSink rtermSink;
// Single cross-core hop for relayed CLI lines: onWCBCommand (Core 0, WiFi task)
// enqueues; drainRemoteCli (loop, Core 1) dequeues and runs. A FreeRTOS queue
// provides the memory barrier a bare volatile flag would not — same pattern as
// the OTA packet queue.
struct RemoteCliMsg { uint8_t relay; char cmd[200]; };
QueueHandle_t remoteCliQueue = nullptr;

// =============================================================================
//  Pin assignments — RUNTIME, selected by the active board profile
// =============================================================================
//  These were compile-time #defines for the WCB HW 3.2 layout. They are now
//  plain globals set at boot by applyBoardProfile() from rcConfig.boardType, so
//  ONE firmware image runs on both the WCB 3.2 hardware and the NaviCore v2 PCB.
//  Every use site is a runtime .begin()/printf(), so a variable is a drop-in.
//  Initialised to the NaviCore v2 defaults; applyBoardProfile() overwrites them
//  AFTER the config loads and BEFORE any port opens (see setup()).
//  (STATUS_LED_PIN stays a constant — GPIO48 onboard NeoPixel on both boards.)
//
//    Board 0 = NaviCore v2 PCB (default)      Board 1 = WCB HW 3.2
//      SBUS in 4  / SBUS out 5                   SBUS in 5  / SBUS out 4
//      Maestro TX6 / RX7                         Maestro TX6 / RX7
//      S3 (v2 "Serial 1") TX8  / RX9             S3 TX15 / RX16  (WCB "Serial 3")
//      S4 (v2 "Serial 2") TX10 / RX21            S4 TX17 / RX18  (WCB "Serial 4")
//      S5 (v2 "Serial 3") TX38 / RX47            S5 TX9  / RX10  (WCB "Serial 5")
// =============================================================================
enum BoardType : uint8_t { BOARD_NAVICORE_V2 = 0, BOARD_WCB_HW_32 = 1 };

uint8_t SBUS_RX_PIN    = 4;   // Serial1/UART1 RX — SBUS from RC receiver
uint8_t SBUS_OUT_PIN   = 5;   // SBUS OUT TX (UART0/Serial0 dedicated, or shared UART1 TX)
uint8_t MAESTRO_TX_PIN = 6;   // Serial2 TX — local Maestro command bus
uint8_t MAESTRO_RX_PIN = 7;   // Serial2 RX — optional Maestro feedback
uint8_t S3_TX_PIN      = 8;   // Aux serial S3 TX (v2 "Serial 1")
uint8_t S3_RX_PIN      = 9;   // Aux serial S3 RX
uint8_t S4_TX_PIN      = 10;  // Aux serial S4 TX (v2 "Serial 2")
uint8_t S4_RX_PIN      = 21;  // Aux serial S4 RX
uint8_t S5_TX_PIN      = 38;  // Aux serial S5 TX (v2 "Serial 3"; WCB 3.2 "Serial 5" GPIO9/10)
uint8_t S5_RX_PIN      = 47;  // Aux serial S5 RX

// SBUS layout is RUNTIME via the `sbusSharedUart` flag (set by applyBoardProfile();
// replaces the old compile-time SBUS_SHARED_UART):
//   • BOTH current boards (WCB 3.2 and NaviCore v2) use SHARED: SBUS IN + OUT on ONE
//     full-duplex UART (UART1/Serial1), RX SBUS_RX_PIN + TX SBUS_OUT_PIN, 100k 8E2
//     inverted (the invert flag is right for both directions; a non-blocking TX
//     buffer keeps the byte-tee from stalling). That frees UART0 to be the hardware
//     S3 aux port (>57600 capable). NOTE: the shared path is not yet bench-validated.
//   • sbusSharedUart=false is the DEDICATED fallback (SBUS OUT on its own UART0/Serial0,
//     TX-only; S3 then bit-banged SoftwareSerial). Not used by either current board —
//     flip a board's flag in applyBoardProfile() if shared SBUS proves unreliable.

#define STATUS_LED_PIN  48    // onboard NeoPixel — GPIO48 on both WCB 3.2 and NaviCore v2
#define STATUS_LED_COUNT 1

// =============================================================================
//  WCB Client + Streams
//
//  Single shared broadcast stream:  All remote Maestro bytes go out on one
//  WCBStream targeting `broadcast` (target_wcb=0). The Kyber path delivers
//  them to every WCB on the network. Each receiving WCB with Kyber_Remote
//  forwards the raw bytes to its configured Maestro port — no per-slot
//  WCB/port routing needed on the sender.
//
//  No compile-time Maestro instances: Maestro slots (IDs 1-8) are configured
//  at RUNTIME via the GUI's Maestro Locations panel (rcConfig.maestros[]).
//  Each slot decides whether bytes go to Serial2 (local) or the broadcast
//  stream (remote), and which Pololu device # to embed.  See maestroWrite()
//  below for the dispatch.
// =============================================================================
// Heap-allocated in setup() AFTER NVS config loads, so the values come from
// rcConfig.wcbNetwork (GUI-editable) instead of the wcb_config.h #defines.
// The #defines are still the factory defaults on a fresh device — see
// rcConfigLoadDefaults() in rc_config.h.
WCB_Client* wcb = nullptr;
// True ONLY after wcb->begin() succeeds. ESP-NOW is unusable until then, and
// calling send/broadcast/update on a WCB_Client whose begin() failed is
// undefined behavior — so every wcb-> call is gated on this flag.
bool wcbReady = false;

// One stream, broadcast to all WCBs.  target_port is ignored for broadcast.
//
// MUST be constructed AFTER `wcb` (in setup()): WCBStream's constructor
// self-registers with the WCB_Client singleton via WCB_Client::instance(), and
// that registration is what makes wcb->update() drive this stream's flush.
// If it were a global it would construct at static-init time — before the
// heap-allocated WCB_Client exists — and silently fail to register, so no
// Maestro bytes would ever leave the board over ESP-NOW.
WCBStream* maestroBroadcast = nullptr;

// =============================================================================
//  Aux serial ports S3, S4, S5  (shared-SBUS layout)
//
//  ESP32-S3 has 3 hardware UARTs (UART0/1/2).  Allocation once the debug
//  console moved to native USB CDC (USBMode=hwcdc, CDCOnBoot=cdc):
//    • Serial  → native USB CDC (debug + config tool)  — no UART consumed
//    • Serial1 → UART1 → SBUS IN + OUT (shared, 100k 8E2 inverted)
//    • Serial2 → UART2 → local Maestro TX
//    • Serial0 → UART0 → aux S3 (freed because SBUS IN+OUT share UART1)
//  Both current boards use the shared-SBUS layout (sbusSharedUart=true), so the
//  first aux port S3 runs on HARDWARE UART0/Serial0 (can exceed 57600, up to
//  115200); S4 and S5 are bit-banged via SoftwareSerial (≤57600 baud; they never
//  run the 100k SBUS rate). The dedicated-SBUS-out-on-UART0 layout
//  (sbusSharedUart=false) is a kept-but-unused fallback — see applyBoardProfile().
// =============================================================================
// Aux command ports — their TYPE is RUNTIME board-dependent, so they're reached
// through Stream* pointers bound in setup() AFTER applyBoardProfile(). On both
// current (shared-SBUS) boards: s3 = HARDWARE Serial0/UART0, s4 + s5 =
// SoftwareSerial. v2 silkscreen = "Serial 1/2/3"; WCB 3.2 = its "Serial 3/4/5"
// headers (S5 = GPIO9/10). The dedicated-SBUS fallback would make s3 + s4
// SoftwareSerial with s5 = nullptr.
// Two SoftwareSerial instances back whichever slots are software on the active
// board; the core's Serial0 backs s3 on v2. s3IsHw tells applySerialBauds which
// .begin() overload to use. (This replaces the old compile-time #if SBUS_SHARED_UART
// HardwareSerial&/SoftwareSerial alias — that choice is now runtime, per board.)
SoftwareSerial swAux0;      // backing SoftwareSerial A
SoftwareSerial swAux1;      // backing SoftwareSerial B
Stream* s3 = nullptr;       // aux "S3"  (v2 "Serial 1")
Stream* s4 = nullptr;       // aux "S4"  (v2 "Serial 2")
Stream* s5 = nullptr;       // aux "S5"  (v2 "Serial 3" GPIO38/47; WCB 3.2 "Serial 5" GPIO9/10)
bool    s3IsHw = false;     // true when s3 points at the hardware UART0 (Serial0)

// Open/close an aux port, dispatching on hardware-UART vs bit-banged SoftwareSerial.
static inline void auxBegin(Stream* p, bool isHw, uint32_t baud, uint8_t rxPin, uint8_t txPin) {
  if (!p) return;
  if (isHw) ((HardwareSerial*)p)->begin(baud, SERIAL_8N1, rxPin, txPin);
  else      ((SoftwareSerial*)p)->begin(baud, SWSERIAL_8N1, rxPin, txPin, false, 95);
}
static inline void auxEnd(Stream* p, bool isHw) {
  if (!p) return;
  if (isHw) ((HardwareSerial*)p)->end();
  else      ((SoftwareSerial*)p)->end();
}
// SBUS OUT uses the real UART0 (Serial0) — see setup() and SBUS_OUT_PIN above.

// =============================================================================
//  HCR Vocalizer routing
//
//  HCR command strings are the same regardless of transport (Serial or
//  WCB-ESP-NOW) — short ASCII frames like "<SH3,QEH,QT>\n".  hcrFormatCommand()
//  builds them; executeHcrAction() picks the destination (Serial3, Serial4,
//  or a remote WCB) and writes the formatted payload there.
//
//  We deliberately do NOT use the upstream HCRVocalizer library:
//    • Its begin() is the only place it touches Serial — and we never call it
//      (Serial3/4 baud comes from rcConfig.auxBaud via setup()'s begin call).
//    • Its update()/receive() are no-ops without setRefreshSpeed() — which
//      this sketch doesn't call.
//    • Its I2C transport path has known upstream bugs that don't compile on
//      modern ESP32 + GCC 14, and we never use I2C anyway.
//  Eliminating the dependency keeps CI builds clean and removes a third-party
//  library from the install chain.
//
//  S3/S4/S5 are all valid local HCR destinations (S5 = v2 "Serial 3" / WCB 3.2 "Serial 5").
// =============================================================================

// =============================================================================
//  SBUS + RC Config
// =============================================================================
SbusReader sbusRx;
// rcConfig is heap-allocated in EXTERNAL PSRAM (ESP32-S3-WROOM-1 N16R8 = 8 MB).
// With the 15 logical-button slots the struct is ~210 KB — it will NOT fit in
// internal DRAM alongside the WCB stack + the ~96 KB SET_CONFIG JSON parse.
//
// NOTE: EXT_RAM_BSS_ATTR does NOT help here — the stock Arduino-ESP32 core is
// built without CONFIG_SPIRAM_ALLOW_BSS_SEG_EXTERNAL_MEMORY, so the attribute is
// a no-op and the struct lands in .bss → linker "dram0_0_seg overflowed". The
// reliable way on the stock core is to allocate from the PSRAM heap at runtime
// (ps_calloc, at the top of setup()).  The global below is just a 4-byte pointer;
// `rcConfig` is a macro alias (see rc_config.h) so all rcConfig.xxx access is
// unchanged.  Mapping/threshold arrays aren't a hot path (read on button events,
// not per-SBUS-byte), so PSRAM latency is irrelevant.
// REQUIRES Arduino IDE: Tools → PSRAM → "OPI PSRAM" (the N16R8 is OCTAL PSRAM).
// If PSRAM is off, ps_calloc() returns null and setup() halts with a message.
RcConfig* g_rcConfig = nullptr;

// =============================================================================
//  Status LED
// =============================================================================
Adafruit_NeoPixel statusLed(STATUS_LED_COUNT, STATUS_LED_PIN, NEO_GRB + NEO_KHZ800);

void setStatusLed(uint32_t color, uint8_t brightness = 20) {
  statusLed.setBrightness(brightness);
  statusLed.setPixelColor(0, color);
  statusLed.show();
}

static const uint32_t C_RED    = 0xFF0000;
static const uint32_t C_GREEN  = 0x00FF00;
static const uint32_t C_BLUE   = 0x0000FF;
static const uint32_t C_YELLOW = 0xFFFF00;
static const uint32_t C_ORANGE = 0xFF8000;
static const uint32_t C_CYAN   = 0x00FFFF;
static const uint32_t C_OFF    = 0x000000;

// LED fault latch — tiny arbiter so a fault outranks the routine SBUS status.
// A non-zero color here means "a persistent fault was detected" (currently:
// wcb->begin() failure in setup; future faults can latch their own color).
// updateStatusLed() displays a latched fault STEADY and skips the SBUS
// indication, so last-writer-wins can't silently erase a fault. 0 = no fault.
uint32_t g_ledFaultColor = 0;

// =============================================================================
//  SBUS state
// =============================================================================
int           sbusValues[24]        = {0};
unsigned long sbusFrameCount        = 0;
unsigned long sbusLastFrameMs       = 0;
unsigned long sbusFpsLastSecond     = 0;
unsigned long sbusFpsCounter        = 0;
int           sbusFps               = 0;
bool          sbusFailsafe          = false;
bool          lostFrameOld          = false;
bool          sbusLiveDump          = false;
unsigned long sbusLiveDumpLastMs    = 0;

int oldValueMatrix  = 100;   // raw matrix SBUS value — kept fresh for status/diagnostics
int oldValueMode    = 100;

// ── Matrix-button edge state machine ─────────────────────────────────────────
// Replaces the old raw-value-delta gate (abs(mxVal-oldValueMatrix) >= 5) that
// silently dropped fast re-presses of the same button (the value was identical
// across the two sampled SBUS frames so no "edge" was seen).
//
// Three-state debounced edge machine (NEUTRAL · TRANSITION · BUTTON):
//   • A press is COMMITTED only after the decoded button is stable in-band for
//     rcConfig.matrixDebounceFrames consecutive frames — rejects single-frame
//     noise and analog resistor-ladder sweep transients.
//   • A release/re-arm is COMMITTED only after NEUTRAL (decoded == 0) is stable
//     for matrixDebounceFrames consecutive frames — so a brief 1-frame neutral
//     dip mid-press (sweep slew, contact bounce) can no longer falsely re-arm
//     and split one press into a phantom double.
//   • Anything not yet stable (short neutral blips, unsettled band) is the
//     implicit TRANSITION state: it changes nothing — no fire, no re-arm.
// matrixDebounceFrames is runtime-configurable (Config modal): 1 = fastest
// (clean digital SBUS source), 2-4 for a noisy analog transmitter matrix.
// Only a true sub-frame tap (press+release inside one ~9-14 ms frame interval)
// is unrecoverable — a hard SBUS-protocol limit, not logic.
bool matrixArmed       = true; // true → a confirmed-neutral release has armed the next press
int  matrixCandidate   = 0;    // decoded button currently being debounced
int  matrixCandCount   = 0;    // consecutive frames matrixCandidate has held in-band
int  matrixNeutralCount = 0;   // consecutive NEUTRAL (decoded==0) frames — for release debounce

// =============================================================================
//  Mode state
// =============================================================================
int FunctionSwState = 1;   // 1=down, 2=mid, 3=up

// =============================================================================
//  Pending action queue
// =============================================================================
struct PendingAction {
  bool          active;
  unsigned long fireAt;
  RcAction      action;
};
#define PENDING_ACTION_SLOTS 8
PendingAction pendingActions[PENDING_ACTION_SLOTS];

// =============================================================================
//  USB Serial WebSerial monitor state
// =============================================================================
bool          wsMonitorActive   = false;
unsigned long wsMonitorLastSent = 0;
// While the config tool's calibration wizard is open the operator deliberately
// wiggles every stick/knob/switch/button. Suppress ALL action dispatch while
// this is set so nothing (HCR/Maestro/MP3/WCB/Serial) fires during cal.
// Set/cleared via {"type":"CALIB","on":bool}; also force-cleared by
// STOP_MONITOR and a fresh PING so a crashed/closed page can never leave the
// board permanently muted.
bool          calibrationActive = false;
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
void loop() {
  // WCB — heartbeats, ACKs, WCBStream flushes
  if (wcb && wcbReady) wcb->update();

  // Firmware OTA over the WCB mesh — drain packets the receive callback queued
  // (esp_ota_* blocks, so it can't run in the WiFi task) and reap a stalled
  // session. Both are cheap no-ops when no OTA is in flight.
  naviota::drainOtaPackets();
  naviota::checkOtaTimeout();

  // Remote terminal — run any CLI line relayed from the config tool, with its
  // Serial output tee'd back to the bridge as RTERM packets. Cheap no-op when
  // nothing is pending.
  drainRemoteCli();

  // Record/replay — drain captured events into the PSRAM clip (Core-1 sole
  // writer) and advance any active replay. Both cheap no-ops when idle.
  navirec::pollControl();   // run any Record/Play trigger deferred from dispatch (Core-1 safe)
  navirec::drain();
  navirec::replayTick();
  if (navirec::takeReplayDone()) Serial.println("[REC] ▶ playback complete");

  // WCB-network telemetry bridge — periodic rc_hb (0.5 Hz) + rc_ch (5 Hz)
  // broadcasts so the config tool's "Via WCB" mode can discover and live-
  // monitor this RC.  Event-driven rc_trig / rc_mode are emitted from
  // rcDispatch() and the mode-decode block in processSbus(), respectively.
  rcTelemetry::tick();

  // SBUS
  processSbus();
  checkDeferredTap();

  // Status LED: steady BLUE while receiving SBUS, slow-flash ORANGE when not
  updateStatusLed();

  // Pending delayed actions
  checkPendingActions();

  // USB Serial WebSerial monitor stream
  sendPWMUpdate();

  // USB Serial input
  handleSerialInput();

  // FPS counter
  trackSbusFps();

  // 1Hz SBUS live dump (#L10)
  if (sbusLiveDump && (millis() - sbusLiveDumpLastMs >= 1000)) {
    sbusLiveDumpLastMs = millis();
    dumpSbusState();
  }
}

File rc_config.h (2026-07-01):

#pragma once
// ─────────────────────────────────────────────────────────────────────────────
//  rc_config.h — RC button / switch / knob mapping configuration
//
//  Adapted from Body_Controller_ESP32_GUI for the NaviCore project.
//  Key changes vs. BC version:
//    • Action types: RA_ESPNOW/RA_HCR/RA_ANIM → RA_WCB_UNICAST/RA_WCB_BROADCAST/
//                   RA_MAESTRO_LOCAL/RA_MAESTRO_REMOTE
//    • RA_SERIAL ports: S3/S4/S5 (S3 = hardware UART0, S4/S5 SoftwareSerial;
//      SBUS OUT now shares UART1, freeing the S5 header on both boards)
//    • Knob functions: KF_NONE / KF_MAESTRO_PASSTHROUGH / KF_HCR_VOLUME
//    • Default mappings: empty (all actions user-configured via GUI)
//    • Same NVS namespace "rcfg" and same JSON shape for GET_CONFIG/SET_CONFIG
// ─────────────────────────────────────────────────────────────────────────────
#include <Arduino.h>
#include <Preferences.h>
#include <LittleFS.h>     // config persists as /config.json; keep this header self-contained
#include <ArduinoJson.h>
#include "wcb_config.h"   // provides WCB_MAC_OCT2/3, WCB_PASSWORD, WCB_QUANTITY, WCB_DEVICE_ID used as factory defaults

// ─────────────────────────────────────────────────────────────────────────────
//  Action types
// ─────────────────────────────────────────────────────────────────────────────
enum RcActionType : uint8_t {
  RA_NONE              = 0,
  RA_WCB_UNICAST       = 1,   // wcb.send(boardId, cmd)   — boardId in target[]
  RA_WCB_BROADCAST     = 2,   // wcb.broadcast(cmd)
  RA_MAESTRO_LOCAL     = 3,   // local Maestro on Serial2 — cmd = "setTarget,ch,pos"
                               //   or "goHome" / "stopScript" / "restartScript,n"
  RA_MAESTRO_REMOTE    = 4,   // remote Maestro via WCBStream — target[] = "1"-"4",
                               //   cmd = same format as RA_MAESTRO_LOCAL
  RA_SERIAL            = 5,   // write cmd to S3/S4/S5 (target[] = port label).
  RA_HCR               = 6,   // Human-Cyborg Relations vocalizer command —
                               //   fn/chan/track describe the HCR call.
                               //   Destination (serial port OR WCB ID+port) is
                               //   a GLOBAL setting in RcConfig::hcrDest.
  RA_MP3               = 7,   // SparkFun MP3 Trigger (v2.x) on a WCB. fn = MP3
                               //   function (see RcMp3Fn); track = numeric arg
                               //   (track #, file index, or volume). Sent as a
                               //   ";A,..." WCB command (normal command path,
                               //   unicast) to RcConfig::mp3Dest — the WCB owns
                               //   the MP3 serial wiring (?MP3,S<port>).
  RA_RECORD            = 8,   // Record/replay control — toggle recording. cmd =
                               //   clip name (for the future clip library; the
                               //   current build has one in-RAM clip). NOT captured.
  RA_PLAY              = 9,   // Play a recorded clip. cmd = clip name; fn = loop
                               //   (0=once, 1=repeat). NOT captured. Both defer to
                               //   loop() so a remote (Core-0) trigger is safe.
  RA_STOP              = 10,  // Stop recording (save) OR playback — explicit halt,
                               //   in case you'd rather not use the Record/Play toggle.
};

// MP3 Trigger function codes, stored in RcAction::fn for RA_MP3 actions.
// Map 1:1 to the WCB ";A,<CMD>" command set (WCB_MP3.cpp processMP3AudioCommand).
enum RcMp3Fn : uint8_t {
  MP3_PLAY   = 1,   // ;A,PLAY,<track>     track 1-255
  MP3_PLAYFS = 2,   // ;A,PLAYFS,<index>   index 0-255
  MP3_STOP   = 3,   // ;A,STOP             start/stop toggle
  MP3_NEXT   = 4,   // ;A,NEXT
  MP3_PREV   = 5,   // ;A,PREV
  MP3_VOL    = 6,   // ;A,VOL,<n>          0=loudest .. 64=inaudible
  MP3_VOLUP  = 7,   // ;A,VOLUP
  MP3_VOLDN  = 8,   // ;A,VOLDN
};
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

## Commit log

2026-05-15 Initial commit — extract RC_Controller into standalone repo
    WCB-based RC controller firmware for ESP32-S3 (WCB HW 3.2) with a
    browser-based Web Serial config tool. Previously lived under Arduino-Code/.
2026-05-19 Calibration mute, analog channel auto-detect, live baud, measured thresholds, HyperCore branding
    - Suppress all action dispatch while the calibration wizard is open
    (CALIB message; auto-clears on STOP_MONITOR / PING so a crashed page
    can't leave the board muted)
    - Calibration now auto-detects analog/switch SBUS channels by largest
    swing and saves them; fix LS/RS/SI/SJ channel-0 defaults
    - Apply Serial2/3/4 baud changes live on config save (no reboot needed)
    - Add HCR S3/S4 direct-test CLI commands (#L20 / #L21)
    - Bake in measured X18 SBUS threshold defaults; relabel T3/T2 to
    Up/Down; hide inert button 19 from the threshold table
    - HyperCore logo/header (full logo when sidebar open, w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
    [RC-Controller.ino, rc_config.h]
2026-05-20 UI overhaul + WCB live status + larger cmd buffer
    GUI restructure:
    - Sidebar trimmed to live monitors only (SBUS Receiver, Live PWM Monitor,
    new WCB Status panel)
    - Moved into Config modal: Tap Window, Channel Assignments, Channel
    Thresholds, WCB Send (Test), and the Calibrate RC launcher (renamed
    modal title to "Configuration")
    - Editing Mode now a centered pill bar above the transmitter (no longer
    a boxed sidebar widget)
    - HyperCore wordmark/logo + R2 footer logo (inline with QR + buttons)
    Terminal (WCB-style drawer):
    - Fully hidden by default; opened via top-bar "⌨ Terminal" button
    - Accent border + drop-shadow when open; slim resize bar with grip
    - Unified ghost-small button s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
    [RC-Controller.ino, rc_config.h]
2026-05-21 Browser firmware flasher (WCB v3.2) + firmware versioning (v0.1_DTG)
    - Config → Firmware tab: Update Firmware (NVS preserved) and Full Wipe
    & Flash (factory-fresh) buttons, progress bar, log, current-version
    readout populated from the extended PONG reply.
    - flasher.js: esptool-js wrapper, pulls bins from /firmware/ on GitHub,
    smart blank-vs-programmed-vs-mismatched-partition auto-detect.
    - fw_version.h: single source of truth (FW_VERSION_BASE + FW_VERSION_DTG).
    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
2026-05-21 CI: auto-build firmware bins on push (WCB v3.2 / ESP32-S3)
    - .github/workflows/build-firmware.yml: mirrors the WCB Wizard's build
    pattern. Installs arduino-cli + esp32:esp32@3.3.4, library deps
    (ArduinoJson, NeoPixel, EspSoftwareSerial, PololuMaestro, HCR API,
    WCBClient/WCBStream), runs tools/build-firmware.sh, and commits the
    three .bin files back to firmware/ via stefanzweifel/git-auto-commit-action
    with [skip ci] so the auto-commit doesn't recurse.
    - tools/build-firmware.sh: bash twin of build-firmware.ps1 used by CI
    (and runnable locally on Linux/macOS/WSL). Reads FW_VERSION_BASE +
    FW_VERSION_DTG from fw_version.h so the bin filename matches the
    version baked into the bin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
2026-05-21 Rename WCBClient include to match the public WCBClient repo
    The greghulette/WCBClient library has its header named WCB_Client.h
    (with underscore); RC-Controller.ino was including it as <WCBClient.h>
    which only resolved on the local Arduino sketchbook copy. Switching
    the include to <WCB_Client.h> makes the CI build on Linux work and
    matches the published library exactly.
    [RC-Controller.ino]
2026-05-21 CI: patch HCR API hcr.h to use <string.h> instead of <String.h>
    The upstream HumanCyborgRelationsAPI library's hcr.h includes
    <String.h> (capital S) on line 16. Windows case-insensitive
    filesystems resolve that to <string.h>, but Linux is strict.
    WCB never trips on this because WCB.ino doesn't include hcr.h
    on its compile path; RC-Controller.ino does.
    Surgical sed after the library install — leaves the upstream
    repo untouched.
2026-05-21 Rename WCBClient class to WCB_Client to match public library
    The public greghulette/WCBClient library declares the class as
    WCB_Client (matching its WCB_Client.h header). The local working
    copy in Arduino-Code/libraries/WCBClient/ uses the un-underscored
    name. CI builds the public version, so the .ino has to use the
    public class name.
    Two code sites changed (declaration at line 95, construction at
    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
2026-05-21 CI: patch 5 ESP32 / GCC-14 compat bugs in upstream HCR API
    ESP32 core 3.3.4 + GCC 14 catches latent bugs in hcr.cpp that older
    toolchains let pass. WCB CI doesn't trip on these because WCB.ino
    never includes hcr.h; RC-Controller does. Five surgical edits via a
    Python heredoc, all idempotent:
    1. hcr.h: #include <String.h> → <string.h> (case)
    2. hcr.cpp: _i2c->setWireTimeout(...) → commented out (AVR-only API)
    3. hcr.cpp: (byte)_i2caddr → (uint8_t) (std::byte
    ambiguity under
    C++17/GCC 14)
    4. hcr.cpp: byte ch = _i2c->read()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
2026-05-22 CI: replace HCR regex brace-wrap with safer declaration split
    The previous patch 6 used a non-greedy regex
    (case 0x03:)([\s\S]*?break;\n)(\s*)(default: break;)
    to wrap case bodies in {}. The .*? span spanned across function
    boundaries, swallowing begin()'s case 0x03 plus the rest of begin()
    plus transmit()'s code up to its default: break;, then inserting
    the closing brace inside transmit() — corrupting the whole file.
    Simpler, regex-free fix that addresses the root cause:
    int i2cStatus = 0; (transmit)
    int bytes = _i2c->requestFrom(...); (receive)
    both initialize a POD variable inside a switch case, which makes
    default: break; cross the initia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
2026-05-22 .gitignore: exempt firmware/*.bin so CI auto-commit works
    The previous build succeeded — three bins were produced — but the
    auto-commit step reported "working tree clean" because *.bin was
    gitignored at the top of the file. Adding !firmware/*.bin as an
    explicit exception (parallel to the existing !model/*.bin) lets
    the CI commit the bins back without affecting any other build
    artifacts.
2026-05-22 Drop HCRVocalizer dependency — format HCR commands inline
    RC-Controller already had a hand-rolled hcrFormatCommand() that built
    the exact byte strings HCRVocalizer's methods would have written
    (it existed for the WCB-transport path which doesn't use the library).
    Reuse it for the local-serial path too:
    • #include <hcr.h> → removed
    • HCRVocalizer hcrS3 / hcrS4 globals → removed
    • HCR_BAUD_RATE constant → removed (was already
    documented as a dead
    parameter — never used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
    [RC-Controller.ino]
2026-05-22 Build: simplify FQBN to Arduino IDE defaults so Serial routes via UART0
    My previous FQBN forced USBMode=hwcdc + CDCOnBoot=cdc, routing Serial
    to the ESP32-S3's native USB-Serial-JTAG controller (GPIO 19/20). The
    WCB v3.2 doesn't expose those native USB pins for debug — its USB
    connector reaches the ESP32-S3 via a USB-to-UART bridge wired to
    UART0. With my override, Serial.println() output went out the wrong
    endpoint (silently invisible), even though the firmware was running
    fine (LED reached blue / setup completed).
    Matching the WCB workflow's approach: FQBN now just
    `esp32:esp32:esp32s3:PartitionScheme=min_spiffs`, all other menu
    options at their Arduino IDE defaults. That's USBMode=defa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
2026-05-22 CI: pin ArduinoJson@7.4.3 + NeoPixel@1.15.4 to match local installs
    Symptom: SET_CONFIG was returning "parse failed" on the CI build
    while everything else (PING, GET_CONFIG, START_MONITOR) worked. Local
    bench builds compiled from the same source had no such issue.
    Root cause: ArduinoJson major-version mismatch.
    • Greg's local: 7.4.3
    • CI was pinned at: 6.21.5
    ArduinoJson 6.x allocates DynamicJsonDocument(98304) as a single
    contiguous 96 KB block up front. After WiFi + ESP-NOW + USB stack
    are all initialized, the ESP32-S3 heap is fragmented enough that
    the allocation can fail — surfacing as deserializeJson() returning
    NoMemory, which the SET_CONFIG handler reports as "parse failed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
2026-05-22 Move SBUS OUT passthrough from SoftwareSerial to Serial1 hardware TX
    Fixes the post-boot "Stack canary watchpoint triggered (IDLE0)" crashes
    that happened seconds-to-minutes after SBUS was connected.
    Diagnosis: addr2line on the recurring backtrace pointed at
    EspSoftwareSerial::UARTBase::write(byte) spinning in micros() — i.e.
    every incoming SBUS byte (113 fps × 25 bytes = ~2825 bytes/sec) was
    being bit-banged out GPIO9 via SoftwareSerial. At 100k baud that's
    ~110µs of busy-wait per byte, ~31% of one core glued continuously
    to bit-banging with interrupts disabled inside the critical sections.
    That starved Core 0's IDLE task long enough for its small stack to
    get blown by the next thing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
    [RC-Controller.ino]
2026-05-22 Diagnostic: disable SBUS OUT passthrough entirely
    Previous commit moved SBUS OUT from SoftwareSerial to a hardware UART
    TX FIFO. That delayed but did not eliminate the IDLE0 stack-canary
    crashes — board now runs ~a minute under sustained SBUS input before
    panicking.
    This commit disables the SBUS OUT path entirely (txPin=-1, no
    passthrough sink set) as a bisection step:
    • If the board now runs indefinitely under SBUS input, then some
    aspect of the SBUS-OUT write path is still implicated and we'll
    need a different fix (rate-limit, batched flush, no-op for empty
    TX FIFOs, etc.).
    • If it still crashes, the culprit is in SBUS RX / dispatch /
    something downstream of Sb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
    [RC-Controller.ino]
2026-05-22 Calibration: never auto-capture switches — always require Capture click
    Symptom: 3-position switches advanced to the next calibration step the
    moment the user flicked from position 1 to position 2, never letting
    them exercise position 3.
    Root cause: CALIB_SWING_AUTO is 600 SBUS counts. A 3-position SBUS
    switch's positions are at ~172 / 992 / 1811, so moving 1→2 produces
    a swing of ~820 — already over the auto-capture threshold.
    Fix: exclude `step.type === 'switch'` from the auto-capture condition.
    Switches now always wait for an explicit Capture click, matching the
    prior remembered behaviour ("toggle through all positions, then click
    Next"). Buttons, knobs, sliders, and joystick ax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
2026-05-22 Add #L13 raw-SBUS-frame hex dump for CH17-24 diagnosis
    Symptom: live PWM_UPDATE consistently reports CH17-24 = 0 even when
    SJ / LS / RS are exercised on the transmitter. Previously these
    channels were working (per Greg), so something changed — but
    sbus_reader.h hasn't been touched since the initial commit and the
    only RC-Controller.ino changes touching SBUS were OUT-direction
    only. The remaining ambiguity is: are bytes 23-33 of the SBUS-24
    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
2026-05-22 Joystick: rename J3/J4 to xyxy convention (J3=L-X/RUD, J4=L-Y/THR)
    J1-J4 now follow X-then-Y order for each stick:
    J1 = R-stick X (AIL) ← unchanged
    J2 = R-stick Y (ELE) ← unchanged
    J3 = L-stick X (RUD) ← was L-Y (THR)
    J4 = L-stick Y (THR) ← was L-X (RUD)
    Changes:
    • knobDefaults: J3/J4 friendly labels and default channels swapped
    (defaults now AETR: J3=ch4=RUD, J4=ch3=THR).
    • SVG transmitter model: J3 label moves to the "left of cap" position
    (X-axis indicator), J4 to "above cap" (Y-axis indicator). Matches
    the right gimbal where J1 sits beside cap and J2 above.
    • Comment block updated to reflect new positions and the
    above=Y / beside=X vi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
2026-05-22 Calibration: disable auto-capture for all non-buttons + add manual channel input
    Two related changes addressing the same UX complaint ("we auto-advanced
    through LS to RS without me clicking anything; same problem with joysticks").
    1. Auto-capture now BUTTONS ONLY.
    Previously, switches were excluded but knobs / sliders / joystick axes
    still auto-captured on a confident swing. That fired prematurely
    on mid-sweep readings. Switches / knobs / sliders / joysticks now all
    require an explicit Capture click. After Capture, the autoAdvance
    setting still applies (900 ms delay then Next →) — so the only
    behaviour change is "must click Capture to commit."
    2. Manual channel inp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
2026-05-22 Calibration: fix J3 default channel, add pre-flight + joystick warnings, SA/SB fallback
    Three fixes after observing live calibration behaviour:
    1. Revert J3/J4 default channels. My previous AETR-based swap assumed
    L-stick X on CH4 / L-stick Y on CH3, but Greg's TX actually sends
    L-stick X on CH3 / L-stick Y on CH4 (i.e. it's not standard AETR).
    J3 friendly label and SVG position stay as X axis; only the default
    channel changes back to 3 (and J4 back to 4).
    2. SA/SB manual-input fallback. If config.switches[name] exists but its
    `.channel` is 0 (uncalibrated state), the previous fallback chain
    short-circuited there and never reached switchDefaults — so the
    pre-popula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
2026-05-22 Add per-knob "Reverse direction" toggle (knobs / sliders / joystick axes)
    Each analog source (S1, S2, LS, RS, J1-J4) now has a boolean `reverse`
    flag. When true, processKnobs() inverts the SBUS reading around the
    midpoint (1983 - raw, where 1983 = SBUS min 172 + max 1811) BEFORE the
    per-output posMin/posMax mapping runs. Net effect: stick pushed "up"
    dispatches the value that would otherwise be sent for "down."
    Wired through:
    • RcKnob struct: new bool reverse field; defaulted to false on init
    • rcConfigToJSON / rcConfigFromJSON: serialize + parse "reverse"
    • saveConfigToNvs / loadConfigFromNvs (knobs blob): same
    • processKnobs(): flip raw before sbusToRange when kn.reverse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
    [RC-Controller.ino, rc_config.h]
2026-05-22 Gimbal animation: swap left-gimbal X/Y to match the J3=X / J4=Y convention
    The xyxy rename moved J3 to L-stick X (RUD) and J4 to L-stick Y (THR),
    but the SVG gimbal animation still had the OLD wiring:
    moveGimbal('leftGimbalCap', ..., 'J4', 'J3', ...)
    ^^^^ ^^^^
    xName yName
    That fed J4 (now Y axis) into the X argument and J3 (now X axis) into
    Y, so on screen the left stick moved up/down when the operator
    pushed left/right, and vice versa. Calibration was correct — only the
    visual animation was crossed.
    Fixed by swapping the parameters to `'J3', 'J4'`. Right gimbal
    (J1/J2) was already correct and is untouched.
    Co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
2026-05-22 Apply per-knob reverse to the live SVG animation too
    Previously the "Reverse direction" toggle only affected the firmware's
    dispatch path (Maestro / HCR outputs). The on-screen transmitter SVG
    animation kept reading the raw SBUS values from PWM_UPDATE and ignored
    the reverse flag — so toggling reverse for a stick had no visible
    effect on the on-screen gimbal cap, even though it would have flipped
    any actually-dispatched action.
    Added a `knVal(name, raw)` helper inside updateTransmitterAnimation
    that mirrors the firmware's flip (1983 - raw) when the named knob has
    `reverse: true` in config. Used it in three places:
    • S1 / S2 knob indicator rotation
    • LS / RS slider handle positi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
2026-05-22 Calibration highlight: switch from --accent (blue) to --yellow for contrast
    The "press THIS control" calibration highlight previously used the
    same blue family (--accent #0b91eb) as the existing "this control
    has actions configured" fill (--accent2 #1495c0). On any
    already-configured button / switch the highlight was almost
    invisible — the user couldn't tell which one the wizard was
    asking them to press.
    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
2026-05-22 Bump version to v0.2.0 (three-digit semver) + move version display to TX screen
    Version bump:
    • FW_VERSION_BASE: "v0.1" → "v0.2.0". Comment in fw_version.h now
    documents the semver MAJOR.MINOR.PATCH convention explicitly.
    • All script regexes already use `[^"]+` so they handle any quoted
    string — no script changes were required. Documentation comments
    in build-firmware.ps1 + firmware/README.md updated for clarity.
    Screen relocation:
    • Replaced the bottom decorative "WCB / Maestro / Click any button…"
    label inside the transmitter SVG screen with a proper two-line
    version readout:
    UI: v0.2.0
    FW: <populated from board's PONG reply>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
2026-05-22 Multi-transmitter model framework — adds Twin X-Lite alongside X18
    Firmware (rc_config.h):
    • New RcTxModel enum — TX_MODEL_X18 = 0, TX_MODEL_TWIN_X_LITE = 1.
    • RcConfig.txModel field, defaulted to TX_MODEL_X18.
    • JSON serialise / deserialise ("txModel" key) and NVS save / load
    ("tx" preference key). Existing configs without the field load
    as X18 automatically.
    GUI (config_tool/index.html):
    • TX_MODELS metadata table. Each entry lists which controls
    physically exist on that transmitter (buttons[], switches[],
    knobs[]) plus per-control knobDefaults / switchDefaults.
    • knobDefaults / switchDefaults are now let-bindings reassigned by
    applyTxModel(mo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
    [rc_config.h]
2026-05-22 Fix model swap: explicit cssSlug instead of regex-derived class name
    The body-class derivation in applyTxModel() did:
    m.short.toLowerCase().replace(/[^a-z0-9]/g, '')
    For Twin X-Lite that turned 'X-Lite' → 'xlite', producing
    `body.tx-show-xlite`. But the CSS rule + the SVG group class are
    `tx-show-twinxlite` / `.tx-twinxlite`. Mismatch → both groups
    ended up hidden (only X18's rule could ever match), and switching
    to Twin X-Lite produced a blank transmitter pane.
    Added an explicit `cssSlug` field to each TX_MODELS entry that
    matches the existing CSS / SVG class names. Stable, no string-
    manipulation magic.
2026-05-22 Twin X-Lite SVG: redraw body as gamepad shape with flared handles
    The original body path was a rounded rectangle with a small U-notch
    at the bottom — didn't read as a handheld gamepad. Replaced with a
    proper Twin X-Lite silhouette:
    • Narrow top section (x=200-800) where the screen + switches +
    knobs sit, matching the real device's flat top
    • Handles flare OUTWARD at the bottom (down to x=120-880 / y=720),
    rounded grips like the physical gamepad form
    • Deeper U-cutout between the handles where the user's fingers
    wrap around the bottom
    • Antenna stubs poking up from the top corners
    • Highlight-gradient overlay on the upper half for the same 3D
    feel as th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
2026-05-22 Twin X-Lite SVG: widen + raise body top; fix T1/T4 label collision
    Three follow-up fixes after the first body redraw:
    1. Widen + raise the body top so switches and knobs visually attach.
    Old top edge was at y=180, x=200-800. Switch bushings sit at
    y=155 and knob centres at y=135 — all OUTSIDE the body, making
    the controls look like they're floating above empty space.
    New top edge: y=125, x=180-820. Every switch bushing and knob
    centre is now inside the body silhouette, with only the lever
    caps and knob indicator-line tops poking above.
    2. Antennas moved from y=155-183 to y=92-128 so they sit ABOVE the
    new (taller) body, and their stubs are slightly taller.
    3. T1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
2026-05-22 Twin X-Lite SVG v4: real flared handles + bigger rounded top corners
    Previous body had the handles only as small bumps at the bottom corners
    ("ball sac" was an apt description) and a noticeably blocky top edge.
    This redraw fixes both:
    • Upper section: narrower (x=180-820, 640 wide). Hosts the screen,
    six switches, two knobs. Big 40-px-radius rounded corners at the
    top so the rectangle reads as an organic shape rather than a block.
    • Handle flare: from y=395 the silhouette flares OUTWARD via a wide
    curve out to x=75 / x=925 at y=580 — handles are now ~840 px wide
    at their widest, ~200 px wider than the upper body. Each handle
    extends about 340 px tall before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
2026-05-22 Twin X-Lite SVG v5: organic curve traced from the product photo
    Discarded the "narrow top + dramatic flared handles" approach — the
    actual Twin X-Lite silhouette is much more organic:
    • Wider at the bottom than the top, but only modestly (~100 px
    wider at the widest point, not 200 px like the previous flare).
    • The widest point is mid-height in the handle area (y≈530-640),
    not at the very bottom.
    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
2026-05-22 Twin X-Lite SVG: use the user-provided traced vector for the body
    Repeated hand-drawn attempts at the body silhouette weren't matching
    the actual Twin X-Lite shape. Switched to using the vector trace
    the user generated from a product photo via image2vector — saved
    as config_tool/tx-twin-xlite.svg.
    Replaced the hand-drawn body path + highlight overlay + antenna
    stubs with a single <image href="tx-twin-xlite.svg" .../> reference,
    scaled 840 × 614 inside the 1000 × 830 main canvas and positioned at
    (80, 60) so it sits roughly centred with margin top/bottom.
    The trace shows the real silhouette + switches + knobs + sticks +
    screen + handles all in one go. My existing click-zone overlays
    s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
2026-05-22 Twin X-Lite SVG: hand-drawn body matching the reference outline
    Reverted the <image href="tx-twin-xlite.svg"> approach — Greg wanted
    the trace as a REFERENCE only, not embedded directly. Removed the
    trace file from the repo too.
    Hand-drew the body with a path that approximates the reference's
    proportions:
    • Modest outward bulge in the handle area (y=400 → y=540 widens
    from x=180/820 to x=145/855 — about 70 px per side, gentle)
    • Widest point at mid-handle (~y=540), not at the bottom
    • Rounded handle bottoms curving inward at y=720-745
    • Shallow notch at bottom centre (y=705 dip) — NOT a deep
    gamepad-style U-cut
    • 40-px-radius top corners, flat top edge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
2026-05-23 Twin X-Lite SVG: full layout matching reference photo + X18 parity
    - Body silhouette swapped to Greg's hand-drawn outline
    (Images/twinoutline.svg) baked into the 1000x830 canvas
    - Layout: two D-pad trim crosses (T3+T4 left, T2+T1 right) flanking
    a power-button visual; T5/T6 split into Left/Right button pairs;
    bottom row of T5 | B1-B4 | T6
    - Each D-pad arm is its OWN matrix slot, matching X18 conventions
    (slots 7-18) so calibration walks each direction separately and
    modal labels come from BTN_LABELS_DEFAULT (no X-Lite override
    needed any more)
    - Gimbals spread to (240, 400) / (760, 400); moveGimbal() updated
    - TX_MODELS[X-Lite].buttons expanded to all 16 used slots so
    calibrati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
2026-05-23 Add Twin X-Lite reference images and outline SVG
    - twinoutline.svg: Greg's hand-drawn outline (Inkscape) used as the
    source for the X-Lite body silhouette path - the d attribute was
    scaled by 6.358x and translated into the 1000x830 GUI canvas, then
    baked into config_tool/index.html.
    - twinoutline.png: tracing-reference raster embedded in the Inkscape file.
    - x-lite twin.jpg: FrSky Twin X-Lite product photo used as the
    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
2026-06-09 trying to fix booting reliability with custom bootloader
    [NaviCore.ino, rc_config.h]
2026-06-15 updates
    bug fixes and full hcr support added
    [NaviCore.ino, rc_config.h, sbus_reader.h]
2026-06-18 wokring on custom pcb
    [NaviCore_V1.kicad_pcb, NaviCore_V1.kicad_sch]
2026-06-25 Stop tracking KiCad auto-backups; add PCB/.gitignore
    Removes the 14 *-backups/ archives, the autosave + its lock, and the
    regenerable fp-info-cache from version control (all kept on disk), and adds
    PCB/.gitignore so KiCad's transient files stay out of the repo. The real
    design files (.kicad_pcb/.kicad_sch/.kicad_pro) and exported Gerbers stay
    tracked.
2026-06-25 updates
    pcb selector
2026-06-26 updates to support multiple pcbs and changed sbus out
2026-06-26 bug review and fixes.
    [NaviCore.ino, rc_config.h]
2026-07-01 pahse 2 for recording
    [partitions.csv]
